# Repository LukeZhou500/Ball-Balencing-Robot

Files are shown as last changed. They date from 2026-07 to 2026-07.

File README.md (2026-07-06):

# Ball Balancing Robot

## Overview
This is my ball balancing robot project.

I built it mainly for fun and for the learning experience.

The robot’s only purpose is to balance a ball on a glass/acrylic platform. It might seem simple, but it actually requires tight integration between computer vision, inverse kinematics, PID control, and motor control systems.

## Project Video
Here is a video showing the build and explanation:

Ball Balancing Robot Video (https://www.youtube.com/watch?v=7ntZtRzPJNo)

I was inspired to make this robot after seeing this video: https://www.youtube.com/watch?v=KnYSuQEBGHc, but everything in my robot was designed from scratch by me.

## Development Notes
AI assistance was used for debugging and library/syntax support.

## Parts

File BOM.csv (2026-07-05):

Item Name | Qty | Price (total) (USD) | Item link | Notes
Raspberry Pi 4B + SD card + powersupply | 1 | ~100 | Too generic for link | Doesn't have to be a 4b, but it shouldnt be too much weaker because the computer vision is heavy
Wide angle camera | 1 | ~15 | https://www.amazon.com/Raspberry-Camera-Module-160FOV-Fisheye/dp/B083XMGSVP/ref=sr_1_3?sr=8-3 | FOV of around 160 would be good
Screws | 4 M2, 10+ M3, 3+ M4 | ~10 | https://www.amazon.com/Assortment-M2-M3-M4-M5/dp/B0DBLCHK48/ref=sr_1_9?sr=8-9 | If you don't have any screws I recomend gettting a kit with assorted screw lengths with M2, M3, M4
20 KG servo | 3 | 20 each | Too generic for link | A decent 20kg standered servo
3D printed parts | See CAD | Varies, estimate 20 | Too generic for link
Acrylic Panel 6in diameter 1/4 depth | 1 | 10 | https://www.amazon.com/Plexiglass-Diameter-Acrylic-Circle-Backdrop/dp/B09ZSYX99P/ref=sr_1_5?sr=8-5 | Amazon 2 kit but only 1 needed

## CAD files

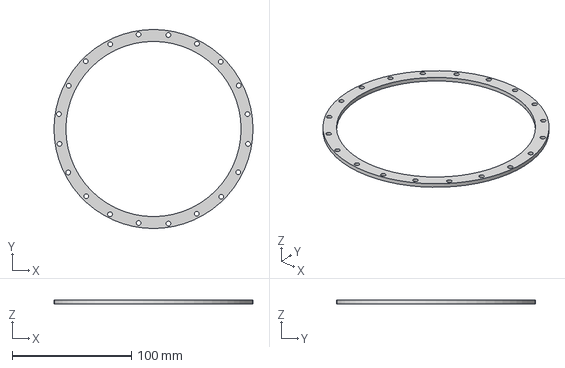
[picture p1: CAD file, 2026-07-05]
CAD/PlatformMountLid.step
167.0 x 167.0 x 3.00 mm

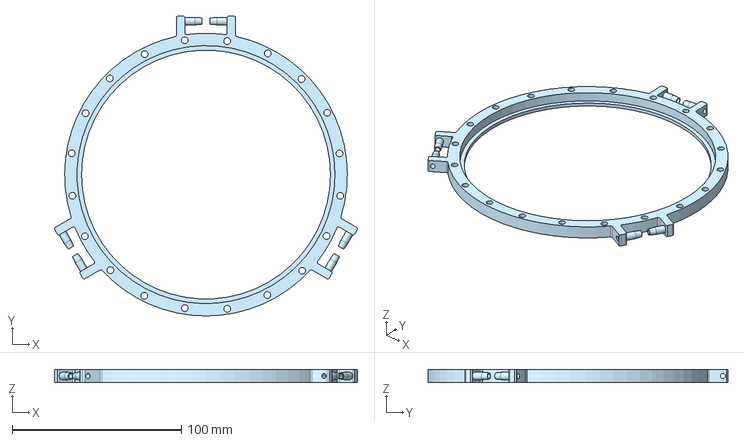
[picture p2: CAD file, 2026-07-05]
CAD/PlatformMount.step
179.0 x 177.1 x 7.60 mm

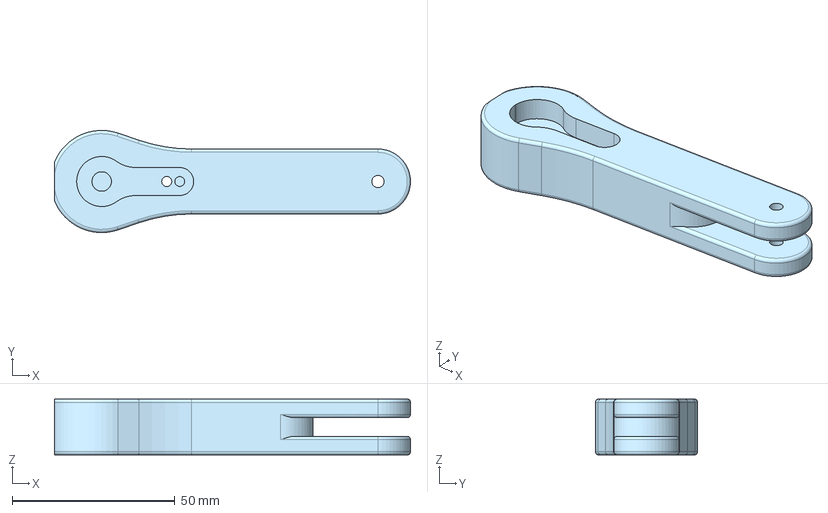
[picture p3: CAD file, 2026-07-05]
CAD/LowerArm.step
109.5 x 31.4 x 17.2 mm

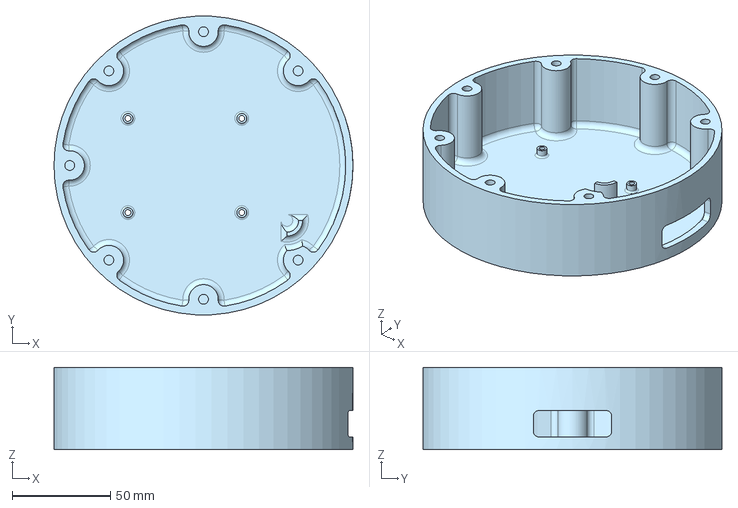
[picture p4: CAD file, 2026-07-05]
CAD/Pi holder baseplate.step
152.4 x 152.2 x 42.0 mm

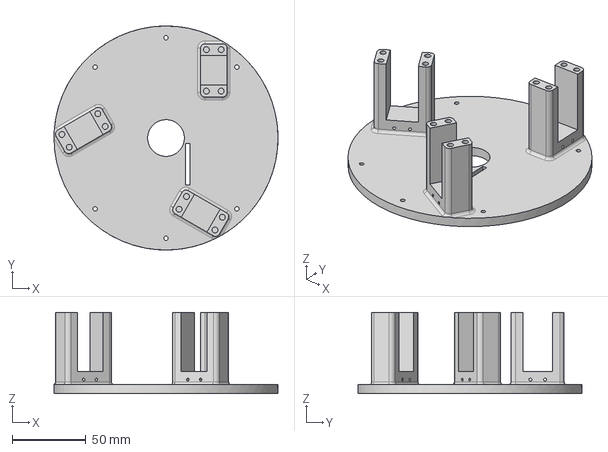
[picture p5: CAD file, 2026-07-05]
CAD/ServoMount.step
152.4 x 152.4 x 55.2 mm

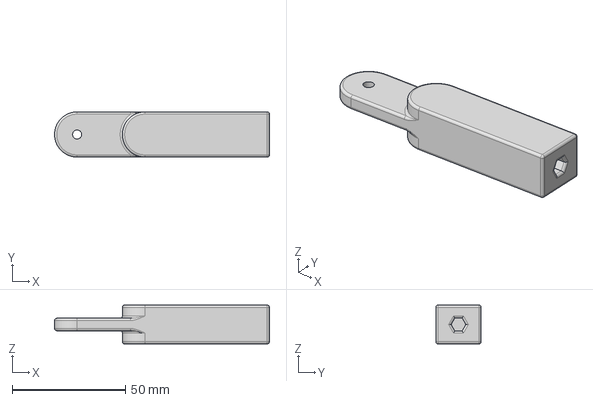
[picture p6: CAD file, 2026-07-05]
CAD/UpperArms.step
95.0 x 20.0 x 17.2 mm

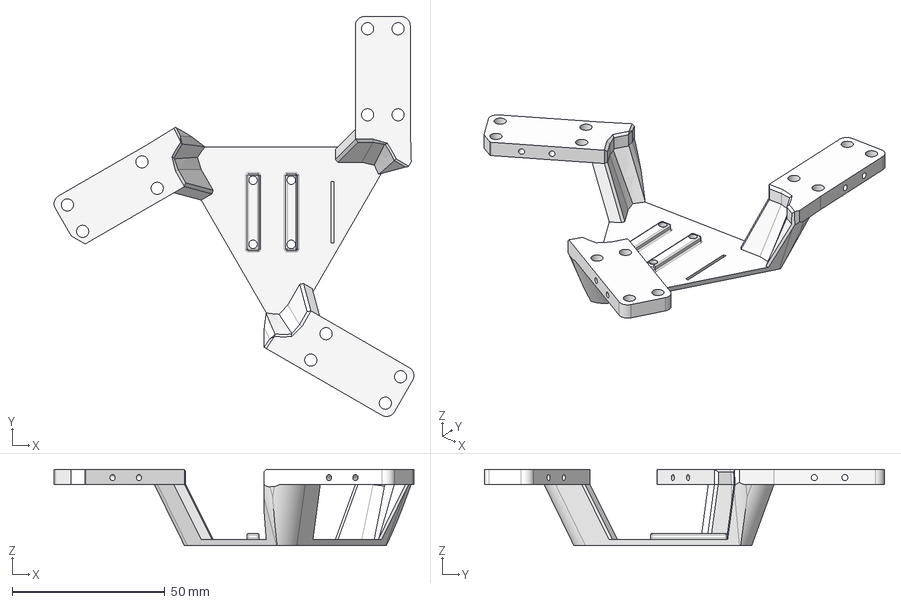
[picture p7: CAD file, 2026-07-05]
CAD/Camera mount.step
117.9 x 131.0 x 25.0 mm

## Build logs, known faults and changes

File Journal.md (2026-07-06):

# Major Progress Log

---

## Major progress #1 — Very early attempt — 11-10-2024

I managed to get an OV7670 camera to work with my Arduino UNO. In this screenshot there are multiple images that are supposed to make up a video stream. I was trying to use computer vision to detect the circle on the image.  
Obviously this Arduino was not going to be powerful enough to do what I needed, but I would estimate I spent around 5 hours to get this far (using a camera with an Arduino UNO was not easy).



---

## Major progress #1.5 — Raspberry Pi — 12-25-2024

I got a Raspberry Pi, so I could use a camera with more than 3 FPS. This was my first time ever using a Raspberry Pi, or any Linux computer so there were many challenges.

Note: During this period I did not have a phone, and I have fully reinstalled my Raspberry Pi OS, so I don't have much pictures.

---

## Major progress #2 — Working camera Raspberry Pi — 3-1-2025

I got the Raspberry Pi's camera to work. I struggled a lot with the operating system version of Bookworm vs Bullseye. Since I used a Raspberry Pi 4, and most tutorials were for a Pi 5 I couldn't find any way to get the camera to work with the latest Raspberry Pi OS. I decided to just use a legacy version, and it worked. I also remember wasting I think 2 full weeks troubleshooting why the camera wouldn't work, and it was because I needed to include sudo.

---

## Major progress #3 — First "Functioning" Model — 5-28-2025

I had the idea that I should make the robot as cheap as possible, but this ended up in the robot being pretty bad.



In this picture it shows the CAD model of the arm. I tried 3D printing my own ball joint (I actually spent so much time on this, I had like 100+ prints), and its tolerances were either too big and the robot would just fall down, or it would be too tight and the 3D printed parts would be stuck together.



This picture shows the CAD model of the base, the 3 rectangular sections are meant to hold the servo. I was also using MG90 servos (cheap tiny servos), and they were not even strong enough to lift the platform.

---

## Major progress #4 — Better servo — 7-5-2025

Watch the video (https://github.com/user-attachments/assets/66a18712-17ef-4c83-ba56-ccc3214245ea)

---

## Major progress #5 — Complete remodel — 7-9-2025

Watch the video (https://github.com/user-attachments/assets/3edda55c-6e69-4948-bfae-6c81fb5bd675)

---

## Major progress #6 — Inverse kinematics — 7-15-2025

I implemented the inverse kinematics into the robot. I actually had experience working with inverse kinematics (from a pen plotter project), but the inverse kinematics for this robot was much much more complex. Luckily this 3-RRS mechanism is somewhat common, and I was able to find a very good website solving the inverse kinematics: https://www.george-yuanji-wang.xyz/blog/3rrs

---

## Major progress #7 — Actually good design — 7-20-2025

Watch the video (https://github.com/user-attachments/assets/80a28c44-ffd9-41d4-be03-82f9cb3cf3cc)

---

## Major progress #8 — OpenCV and computer vision — 8-16-2025

I started tuning the computer vision. The main strategy was to have the ball be bright green, and have a black and white background. I spent a very long time blindly adjusting HSV values, but not surprisingly that did not work well. Then I had a breakthrough where I displayed the min and max ranges of the HSV values, and the real HSV values that the camera was detecting. This allowed me to pinpoint the values that needed adjusting, and I could finally detect the ball.

IMG_0760_(2)

---

## Major progress #10 — PID — 8-25-2025

Watch the video (https://github.com/user-attachments/assets/ee772e6e-aaa9-4394-bfa0-724793c38a50)

This was actually my first time tuning PID, so I made a pretty simple but devastating mistake where the error/offset was always positive. This made it so that no matter how I tuned it, it would still be unstable. In the end I managed to tune the PID so that it can balance the ball.

Mission success.

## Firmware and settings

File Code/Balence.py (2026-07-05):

#!/usr/bin/python3
import time
import math
import cv2
import numpy as np
from picamera2 import Picamera2
from collections import deque
import pigpio
import RPi.GPIO as GPIO

# --- OpenCV global speed knobs ---
cv2.setUseOptimized(True)
cv2.setNumThreads(4)

# === PID & robot imports ===
from Pid import PIDController   # <-- use the stripped version here
from robotKinematics import RobotKinematics

# === Tuning / constants ===
centerX = 90
centerY = 65
chill_range = 0
chillnumb = 30
last_time=0
TARGET_DT = 0.015

lastErrorX = 0
lastLastErrorX = 0
lastLastLastErrorX = 0
errorX = 0

lastErrorY = 0
lastLastErrorY = 0
lastLastLastErrorY = 0
errorY = 0

pid_x = PIDController(kp=0.06, ki=0.1, kd=0.01,kv=0.025) #p = 0.16 v = 0.06
pid_y = PIDController(kp=0.06, ki=0.1, kd=0.01,kv=0.025)#0.08, 0.05

# === Servo GPIO pins ===
servo1 = 18
servo2 = 13
servo3 = 12

# Start pigpio PWM control
pwm = pigpio.pi()
pwm.set_mode(servo1, pigpio.OUTPUT)
pwm.set_mode(servo2, pigpio.OUTPUT)
pwm.set_mode(servo3, pigpio.OUTPUT)

# Set PWM frequency to 50 Hz (standard for servos)
pwm.set_PWM_frequency(servo1, 50)
pwm.set_PWM_frequency(servo2, 50)
pwm.set_PWM_frequency(servo3, 50)

# Kinematics
robot = RobotKinematics()

class Camera:
    def __init__(self, resolution=(200, 150), format="RGB888"):
        self.picam2 = Picamera2()
        config = self.picam2.create_preview_configuration(
            main={"size": resolution, "format": format},
            controls={"FrameDurationLimits": (8333, 8333)}
        )
        self.picam2.configure(config)

        self.lower_ball = np.array([5, 210, 60], dtype=np.uint8)
        self.upper_ball = np.array([15, 255, 255], dtype=np.uint8)

        self.kernel3 = np.ones((3, 3), np.uint8)
        self.queue = deque(maxlen=16)
        self.queue.append((resolution[0] // 2, resolution[1] // 2))

        self.picam2.start()

    def take_picture(self):
        return self.picam2.capture_array()

    def terminate(self):
        self.picam2.stop()
        self.picam2.close()
        cv2.destroyAllWindows()

    def preprocess(self, image):
        return cv2.cvtColor(image, cv2.COLOR_BGR2HSV)

    def find_stuff(self, hsv_frame):
        mask_ball = cv2.inRange(hsv_frame, self.lower_ball, self.upper_ball)
        mask_dilated = cv2.dilate(mask_ball, self.kernel3, iterations=1)
        mask_eroded = cv2.erode(mask_dilated, self.kernel3, iterations=6)
        mask_dilated2 = cv2.dilate(mask_eroded, self.kernel3, iterations=4)

        contours, _ = cv2.findContours(mask_dilated2, cv2.RETR_EXTERNAL, cv2.CHAIN_APPROX_SIMPLE)
        ball_center = self.queue[-1] if self.queue else (0, 0)

        if contours:
            c = max(contours, key=cv2.contourArea)
            area = cv2.contourArea(c)
            if area > 30:
                x, y, w, h = cv2.boundingRect(c)
                ball_center = (x + w // 2, y + h // 2)

        self.queue.append(ball_center)
        return ball_center

def moveServo(thetaX,thetaY,H):
    #print(thetaX,"thetay",thetaY)
    if thetaX < 2 and thetaY < 2 and thetaX> -2 and thetaY >-2:      
        nx = math.sin(thetaX)*-1
        ny = math.sin(thetaY)
        nz = math.cos(math.sqrt(thetaX**2 + thetaY**2))
        #print(nx,"ny",ny,"nz",nz)
        # normalize to unit vector
        norm = math.sqrt(nx*nx + ny*ny + nz*nz)
        #print(norm)
        if norm == 0:
            norm = 1
        nx, ny, nz = nx/norm, ny/norm, nz/norm
        #print(nx,"ny",ny,"nz",nz)
        
        
        # use your current platform height
        h = H
        if nz > 0.7:
            robot.solve_inverse_kinematics_vector(nx, ny, nz, h)
            #print("Theta1:", robot.theta1, "Theta2:", robot.theta2, "Theta3:", robot.theta3)
            pwm1 = (-robot.theta1 / (math.pi/2)) * 1000 + 1530
            pwm2 = (-robot.theta2 / (math.pi/2)) * 1000 + 1495
            pwm3 = (-robot.theta3 / (math.pi/2)) * 1000 + 1450
            
            #print("PWM1:", pwm1, "PWM2:", pwm2, "PWM3:", pwm3)
            
            pwm.set_servo_pulsewidth(servo1, pwm1)
            pwm.set_servo_pulsewidth(servo2, pwm2)
            pwm.set_servo_pulsewidth(servo3, pwm3)

if __name__ == "__main__":
    cam = Camera()

    try:
        while True:
            img = cam.take_picture()
            hsv = cam.preprocess(img)
            ball_center = cam.find_stuff(hsv)
            
            current_time = time.time()
            # --- Control logic ---
            lastLastLastErrorX = lastLastErrorX
            lastLastErrorX = lastErrorX
            lastErrorX = errorX
            lastLastLastErrorY = lastLastErrorY
            lastLastErrorY = lastErrorY
            lastErrorY = errorY
            errorX = (centerX - ball_center[0])*0.4+lastErrorX*0.2+lastLastErrorX*0.2+lastLastLastErrorX*0.2
            errorY = (centerY - ball_center[1])*0.4+lastErrorY*0.2+lastLastErrorY*0.2+lastLastLastErrorY*0.2
            #print(errorX,"errorY",errorY)
            if(errorX < 50 and errorY<50): 
                outputX = pid_x.update(errorX,current_time)  # tilt in X
                outputY = pid_y.update(errorY,current_time)  # tilt in Y
                #print(outputX,"ouputY",outputY)
                thetaX = math.radians(outputX)  # tilt in X
                thetaY = math.radians(outputY)  # tilt in Y
                moveServo(thetaX, thetaY, 130.0)
            
            elapsed = current_time - last_time
            sleep_time = TARGET_DT - elapsed
            last_time = current_time
            if sleep_time > 0:
                time.sleep(sleep_time)

    finally:
        cam.terminate()

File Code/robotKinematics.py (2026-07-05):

import math
import numpy as np

# Precomputed constants
SQRT3 = math.sqrt(3)

class RobotKinematics:
    def __init__(self, lp=79, l1=100, l2=80, lb=40, invert=False):
        self.lp = lp    # Radius of Top
        self.l1 = l1    # Top Arm
        self.l2 = l2    # Bottom Arm
        self.lb = lb    # Radius of Bottom
        self.invert = invert  # Whether the arm stays inward or outward

        self.maxh = self.compute_maxh() - 1
        self.minh = self.compute_minh() + 1
        self.p = [0.0, 0.0, self.maxh]
        self.h = (self.maxh + self.minh) / 2
        self.maxtheta = 10

        # Node coordinates
        self.A1 = [0, 0, 0]
        self.A2 = [0, 0, 0]
        self.A3 = [0, 0, 0]

        self.B1 = [0, 0, 0]
        self.B2 = [0, 0, 0]
        self.B3 = [0, 0, 0]

        self.C1 = [0.0, 0.0, 0.0]
        self.C2 = [0.0, 0.0, 0.0]
        self.C3 = [0.0, 0.0, 0.0]

        self.max_theta(self.h)

        self.theta1 = 0
        self.theta2 = 0
        self.theta3 = 0

    def compute_maxh(self):
        return math.sqrt((self.l1 + self.l2) ** 2 - (self.lp - self.lb) ** 2)

    def compute_minh(self):
        if self.l1 > self.l2:
            return math.sqrt(self.l1 ** 2 - (self.lb + self.l2 - self.lp) ** 2)
        elif self.l2 > self.l1:
            return math.sqrt((self.l2 - self.l1) ** 2 - (self.lp - self.lb) ** 2)
        else:
            return 0

    def solve_top(self, a, b, c, h):
        lp, sqrt3 = self.lp, SQRT3
        if not self.invert:
            denom1 = math.sqrt(4*c*c + (a - sqrt3*b)**2)
            denom2 = math.sqrt(c*c + a*a)
            denom3 = math.sqrt(4*c*c + (a + sqrt3*b)**2)

            self.A1 = [-(lp*c) / denom1,
                       (sqrt3*lp*c) / denom1,
                       h + ((a - sqrt3*b)*lp) / denom1]

            self.A2 = [(lp*c) / denom2,
                       0,
                       h - (lp*a) / denom2]

            self.A3 = [-(lp*c) / denom3,
                       -(sqrt3*lp*c) / denom3,
                       h + ((a + sqrt3*b)*lp) / denom3]
        else:
            # Same as above, could share code if invert logic changes later
            denom1 = math.sqrt(4*c*c + (a - sqrt3*b)**2)
            denom2 = math.sqrt(c*c + a*a)
            denom3 = math.sqrt(4*c*c + (a + sqrt3*b)**2)

            self.A1 = [-(lp*c) / denom1,
                       (sqrt3*lp*c) / denom1,
                       h + ((a - sqrt3*b)*lp) / denom1]

            self.A2 = [(lp*c) / denom2,
                       0,
                       h - (lp*a) / denom2]

            self.A3 = [-(lp*c) / denom3,
                       -(sqrt3*lp*c) / denom3,
                       h + ((a + sqrt3*b)*lp) / denom3]

    def solve_middle(self):
        lb, l1, l2, sqrt3 = self.lb, self.l1, self.l2, SQRT3
        a11, a12, a13 = self.A1
        a21, a22, a23 = self.A2
        a31, a32, a33 = self.A3

        # Common function for computing Ci
        def compute_C(p, q, invert=False):
            r = p*p + (4 if invert in (0, 2) else 1)
            s = 2*p*q + (4*lb if invert in (0, 2) else -2*lb)
            t = q*q + (lb*lb if invert in (0, 2) else lb*lb - l2*l2)
            return r, s, t

        # Precompute common expressions
        p1 = (-a11 + sqrt3*a12 - 2*lb) / a13
        q1 = (a11*a11 + a12*a12 + a13*a13 + l2*l2 - l1*l1 - lb*lb) / (2*a13)
        r1 = p1*p1 + 4
        s1 = 2*p1*q1 + 4*lb
        t1 = q1*q1 + lb*lb - l2*l2

        p2 = (lb - a21) / a23
        q2 = (a21*a21 + a23*a23 - lb*lb + l2*l2 - l1*l1) / (2*a23)
        r2 = p2*p2 + 1
        s2 = 2*(p2*q2 - lb)
        t2 = q2*q2 - l2*l2 + lb*lb

        p3 = (-a31 - sqrt3*a32 - 2*lb) / a33
        q3 = (a31*a31 + a32*a32 + a33*a33 + l2*l2 - l1*l1 - lb*lb) / (2*a33)
        r3 = p3*p3 + 4
        s3 = 2*p3*q3 + 4*lb
        t3 = q3*q3 + lb*lb - l2*l2

        if not self.invert:
            c11 = (-s1 - math.sqrt(s1*s1 - 4*r1*t1)) / (2*r1)
            c12 = -sqrt3 * c11
            c13 = math.sqrt(l2*l2 - 4*(c11*c11) - 4*lb*c11 - lb*lb)
            self.C1 = [c11, c12, c13]

            c21 = (-s2 + math.sqrt(s2*s2 - 4*r2*t2)) / (2*r2)
            c22 = 0
            c23 = math.sqrt(l2*l2 - (c21 - lb)**2)
            self.C2 = [c21, c22, c23]

            c31 = (-s3 - math.sqrt(s3*s3 - 4*r3*t3)) / (2*r3)
            c32 = sqrt3 * c31
            c33 = math.sqrt(l2*l2 - 4*(c31*c31) - 4*lb*c31 - lb*lb)
            self.C3 = [c31, c32, c33]
        else:
            c11 = (-s1 - math.sqrt(s1*s1 - 4*r1*t1)) / (2*r1)
            c12 = -sqrt3 * c11
            c13 = math.sqrt(l2*l2 - 4*(c11*c11) - 4*lb*c11 - lb*lb)
            self.C1 = [c11, c12, -c13]

            c21 = (-s2 + math.sqrt(s2*s2 - 4*r2*t2)) / (2*r2)
            c22 = 0
            c23 = math.sqrt(l2*l2 - (c21 - lb)**2)
            self.C2 = [c21, c22, -c23]

            c31 = (-s3 - math.sqrt(s3*s3 - 4*r3*t3)) / (2*r3)
            c32 = sqrt3 * c31
            c33 = math.sqrt(l2*l2 - 4*(c31*c31) - 4*lb*c31 - lb*lb)
            self.C3 = [c31, c32, -c33]

    def solve_inverse_kinematics_vector(self, a, b, c, h):
        lb = self.lb
        self.B1 = [-0.5*lb, SQRT3*0.5*lb, 0]
        self.B2 = [lb, 0, 0]
        self.B3 = [-0.5*lb, -SQRT3*0.5*lb, 0]

        self.solve_top(a, b, c, h)
        self.solve_middle()

        self.theta1 = math.pi/2 - math.atan2(math.sqrt(self.C1[0]**2 + self.C1[1]**2) - lb, self.C1[2])
        self.theta2 = math.atan2(self.C2[2], self.C2[0] - lb)
        self.theta3 = math.pi/2 - math.atan2(math.sqrt(self.C3[0]**2 + self.C3[1]**2) - lb, self.C3[2])

    def solve_inverse_kinematics_spherical(self, theta, phi, h):
        self.h = h
        self.max_theta(h)
        theta = min(theta, self.maxtheta)

        a = math.sin(math.radians(theta)) * math.cos(math.radians(phi))
        b = math.sin(math.radians(theta)) * math.sin(math.radians(phi))
        c = math.cos(math.radians(theta))

        # Instead of try/except, validate inputs
        if not (math.isfinite(a) and math.isfinite(b) and math.isfinite(c)):
            return
        self.solve_inverse_kinematics_vector(a, b, c, h)

    def get_3d_coordinates_and_center(self):
        a1 = np.array(self.A1)
        a2 = np.array(self.A2)
        a3 = np.array(self.A3)
        center = (a1 + a2 + a3) / 3
        return {"A1": a1.tolist(), "A2": a2.tolist(), "A3": a3.tolist(), "center": center.tolist()}

    def max_theta(self, h, tol=1e-3):
        theta_low, theta_high = 0.0, math.radians(20)
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

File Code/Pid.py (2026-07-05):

import math



class PIDController:

    def __init__(self, kp=1.0, ki=0.0, kd=0.0, kv=0.0,

                 integral_limit=10.0,

                 derivative_filter=0.2,   # 0–1 smoothing

                 velocity_cutoff=5.0,    # cutoff freq [Hz]

                 dt_guess=0.01):

        self.kp = kp

        self.ki = ki

        self.kd = kd

        self.kv = kv



        self.integral_limit = integral_limit

        self.derivative_filter = derivative_filter

        self.velocity_cutoff = velocity_cutoff



        self.prev_error = 0.0

        self.prev_time = None

        self.integral = 0.0



        # filtered derivative and velocity

        self.d_error_filtered = 0.0

        self.vel_filtered = 0.0



        self.dt_guess = dt_guess



    def update(self, error, current_time):

        # compute dt

        if self.prev_time is None:

            dt = self.dt_guess

        else:

            dt = max(current_time - self.prev_time, 0.0005)



        # proportional

        p_term = self.kp * error



        # integral (with windup guard)

        self.integral += error * dt

        self.integral = max(-self.integral_limit, min(self.integral, self.integral_limit))

        i_term = self.ki * self.integral



        # derivative (on error)

        d_error = (error - self.prev_error) / dt

        # simple low-pass filter for derivative

        alpha_d = self.derivative_filter

        self.d_error_filtered = (1 - alpha_d) * self.d_error_filtered + alpha_d * d_error

        d_term = self.kd * self.d_error_filtered



        # velocity damping (opposite to error speed)

        # use same filtered derivative as velocity estimate, but with its own cutoff

        rc = 1.0 / (2 * math.pi * self.velocity_cutoff)

        alpha_v = dt / (rc + dt)

        self.vel_filtered = (1 - alpha_v) * self.vel_filtered + alpha_v * d_error

        v_term = self.kv * self.vel_filtered * abs(pow(d_error,0.65))/7



        # save state

        self.prev_error = error

        self.prev_time = current_time


        pidv = p_term + i_term + d_term + v_term
        if abs(pidv) > 40:
            return 40
        else:
            return pidv
